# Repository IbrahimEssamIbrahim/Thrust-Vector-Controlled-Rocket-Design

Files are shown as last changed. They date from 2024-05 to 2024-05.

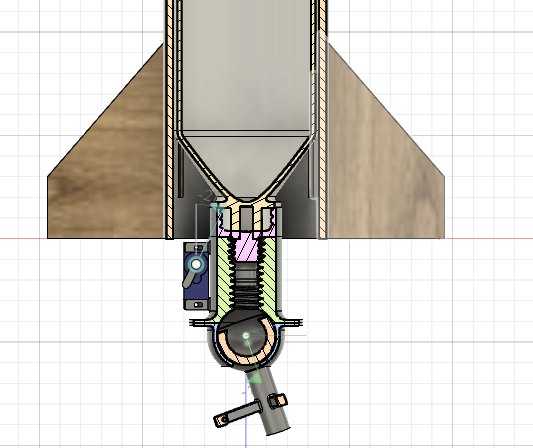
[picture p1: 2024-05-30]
3D&2D_design/3DModels/V0.1/5.png

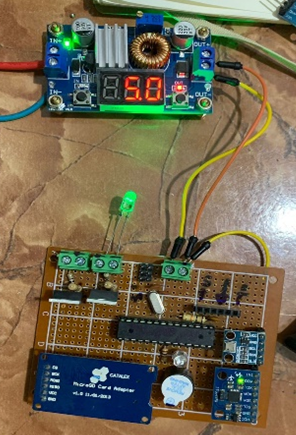
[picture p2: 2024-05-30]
PCBs_RemoteControl_Prototype/PCB_V0.1.png

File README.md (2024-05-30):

# <a href="https://a360.co/3PXAbBp"> Thrust-Vector-Controlled-Rocket-Design </a>

This project proposes the development of a Thrust Vector-Controlled (TVC) rocket as an alternative to drones for high-altitude payload delivery. Drones face limitations such as
cost, payload size restrictions, and reliance on air density, making them inefficient for high-altitude missions. The TVC rocket, inspired by SpaceX's Falcon Heavy, utilizes 
thrust vector control for precise navigation and payload delivery regardless of air density.

The project aims for cost-effectiveness by using off-the-shelf components like pressure sensors, IMUs, and Arduinos, integrated into a single PCB. This approach, coupled with
lightweight 3D-printed materials for the rocket chassis, aims to reduce costs significantly.

Applications include academic research and medical deliveries to remote areas. The rocket's design focuses on stability optimization, utilizing OpenRocket software for
simulations and Fusion 360 for 3D component design. Additionally, a water pressure chamber was introduced for cost-effective testing.

The flight computer comprises various sensors for monitoring acceleration, rotation, and altitude, essential for making critical flight decisions. These include MPU6050 IMUs, 
BMP280 barometers, EEPROMs, and battery level monitors.

Overall, the TVC rocket project offers an affordable and efficient solution for high-altitude payload delivery, potentially revolutionizing academic and humanitarian applications.



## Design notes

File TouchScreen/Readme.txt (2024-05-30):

This file represents an attempt to create a remote touch screen using a TFT 2.4-inch screen. However, the project was discontinued due to limitations with the touch screen module, which occupied all Arduino pins except one. This constraint made it nearly impossible to integrate an NRF transmitter with the Arduino. Instead, the project shifted towards utilizing WiFi with the ESP8266 module.

The TFT 2.4-inch screen libraries contained errors, further complicating the project. While some resources for making the screen work are included in this file, most of the project remains unfinished.

//////////////////////////here is how to solve problem with ///////////////////////////////////

Go to this website to download the library Zip_files ----> 

http://www.lcdwiki.com/2.4inch_Arduino_Display

for better understanding go to ----> https://www.youtube.com/watch?v=_GT_sgbKQrc 

before starting you must make some changes 

in the code change this part 

#define YP A1  // must be an analog pin, use "An" notation!
#define XM A2  // must be an analog pin, use "An" notation!
#define YM 7   // can be a digital pin
#define XP 6   // can be a digital pin 

			TO 

#define YP A3  // must be an analog pin, use "An" notation!
#define XM A2  // must be an analog pin, use "An" notation!
#define YM 9   // can be a digital pin
#define XP 8   // can be a digital pin 

and find Id part and Set it to  --->   tft.begin(0x7575); // SDFP5408

then go to the library file im the documents ---> C:\Users\Ibrahim_Essam\Documents\Arduino\libraries\SPFD5408-master

and change line 163 TO return TSPoint( 1103-x, 1063-y, z);

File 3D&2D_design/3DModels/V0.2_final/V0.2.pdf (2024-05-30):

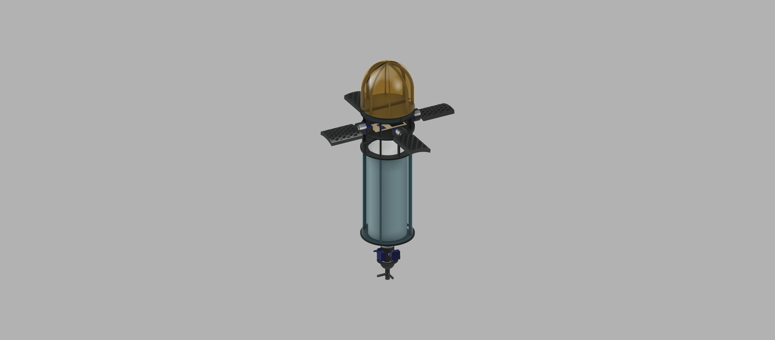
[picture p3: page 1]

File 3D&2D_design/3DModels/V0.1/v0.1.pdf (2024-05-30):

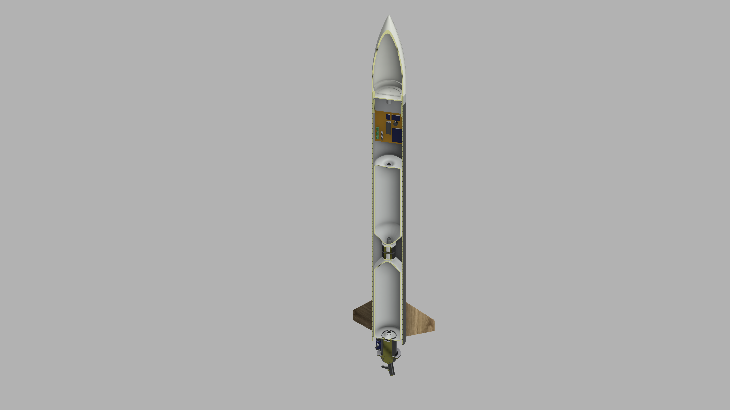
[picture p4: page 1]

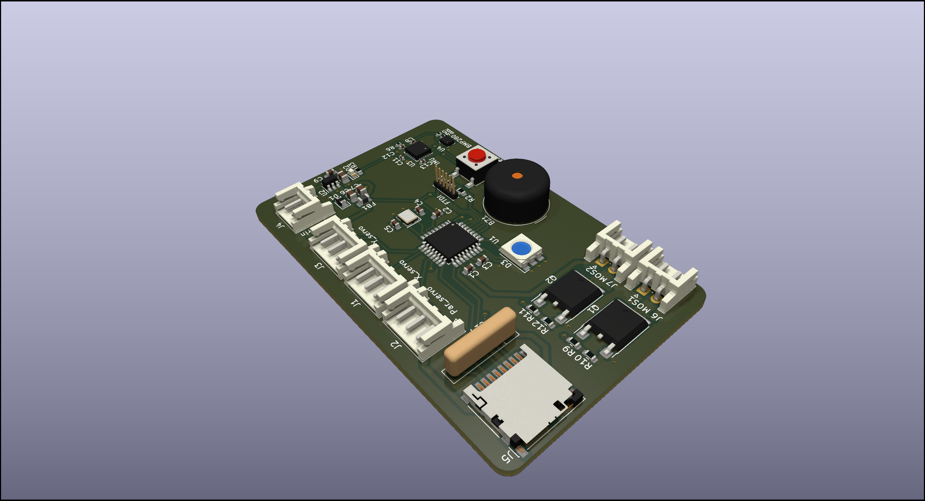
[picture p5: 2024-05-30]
PCBs_RemoteControl_Prototype/3Dview.png

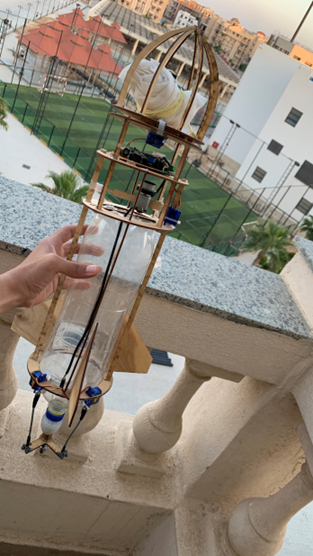
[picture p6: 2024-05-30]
PCBs_RemoteControl_Prototype/final_pro.png

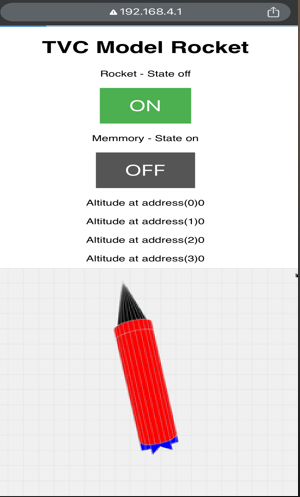
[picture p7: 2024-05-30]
PCBs_RemoteControl_Prototype/WIFI_ControlRemote_withLiveDataView.png

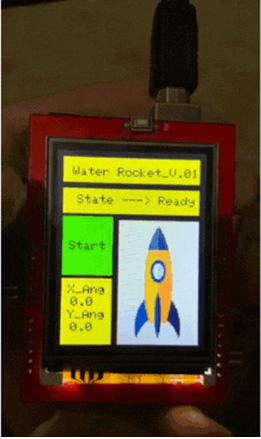
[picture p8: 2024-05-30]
PCBs_RemoteControl_Prototype/RemoteControlWithTouchScreen.png

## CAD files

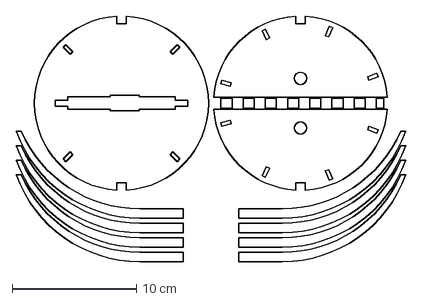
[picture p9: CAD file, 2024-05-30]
3D&2D_design/2D_laserCNC/CNC_Par.dxf
31.3 x 19.7 cm

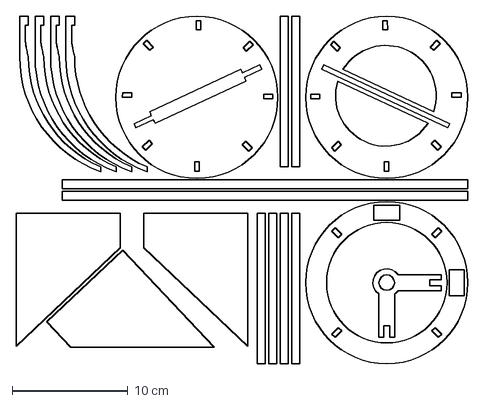
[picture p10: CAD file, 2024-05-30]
3D&2D_design/2D_laserCNC/CNC.dxf
39.0 x 30.0 cm

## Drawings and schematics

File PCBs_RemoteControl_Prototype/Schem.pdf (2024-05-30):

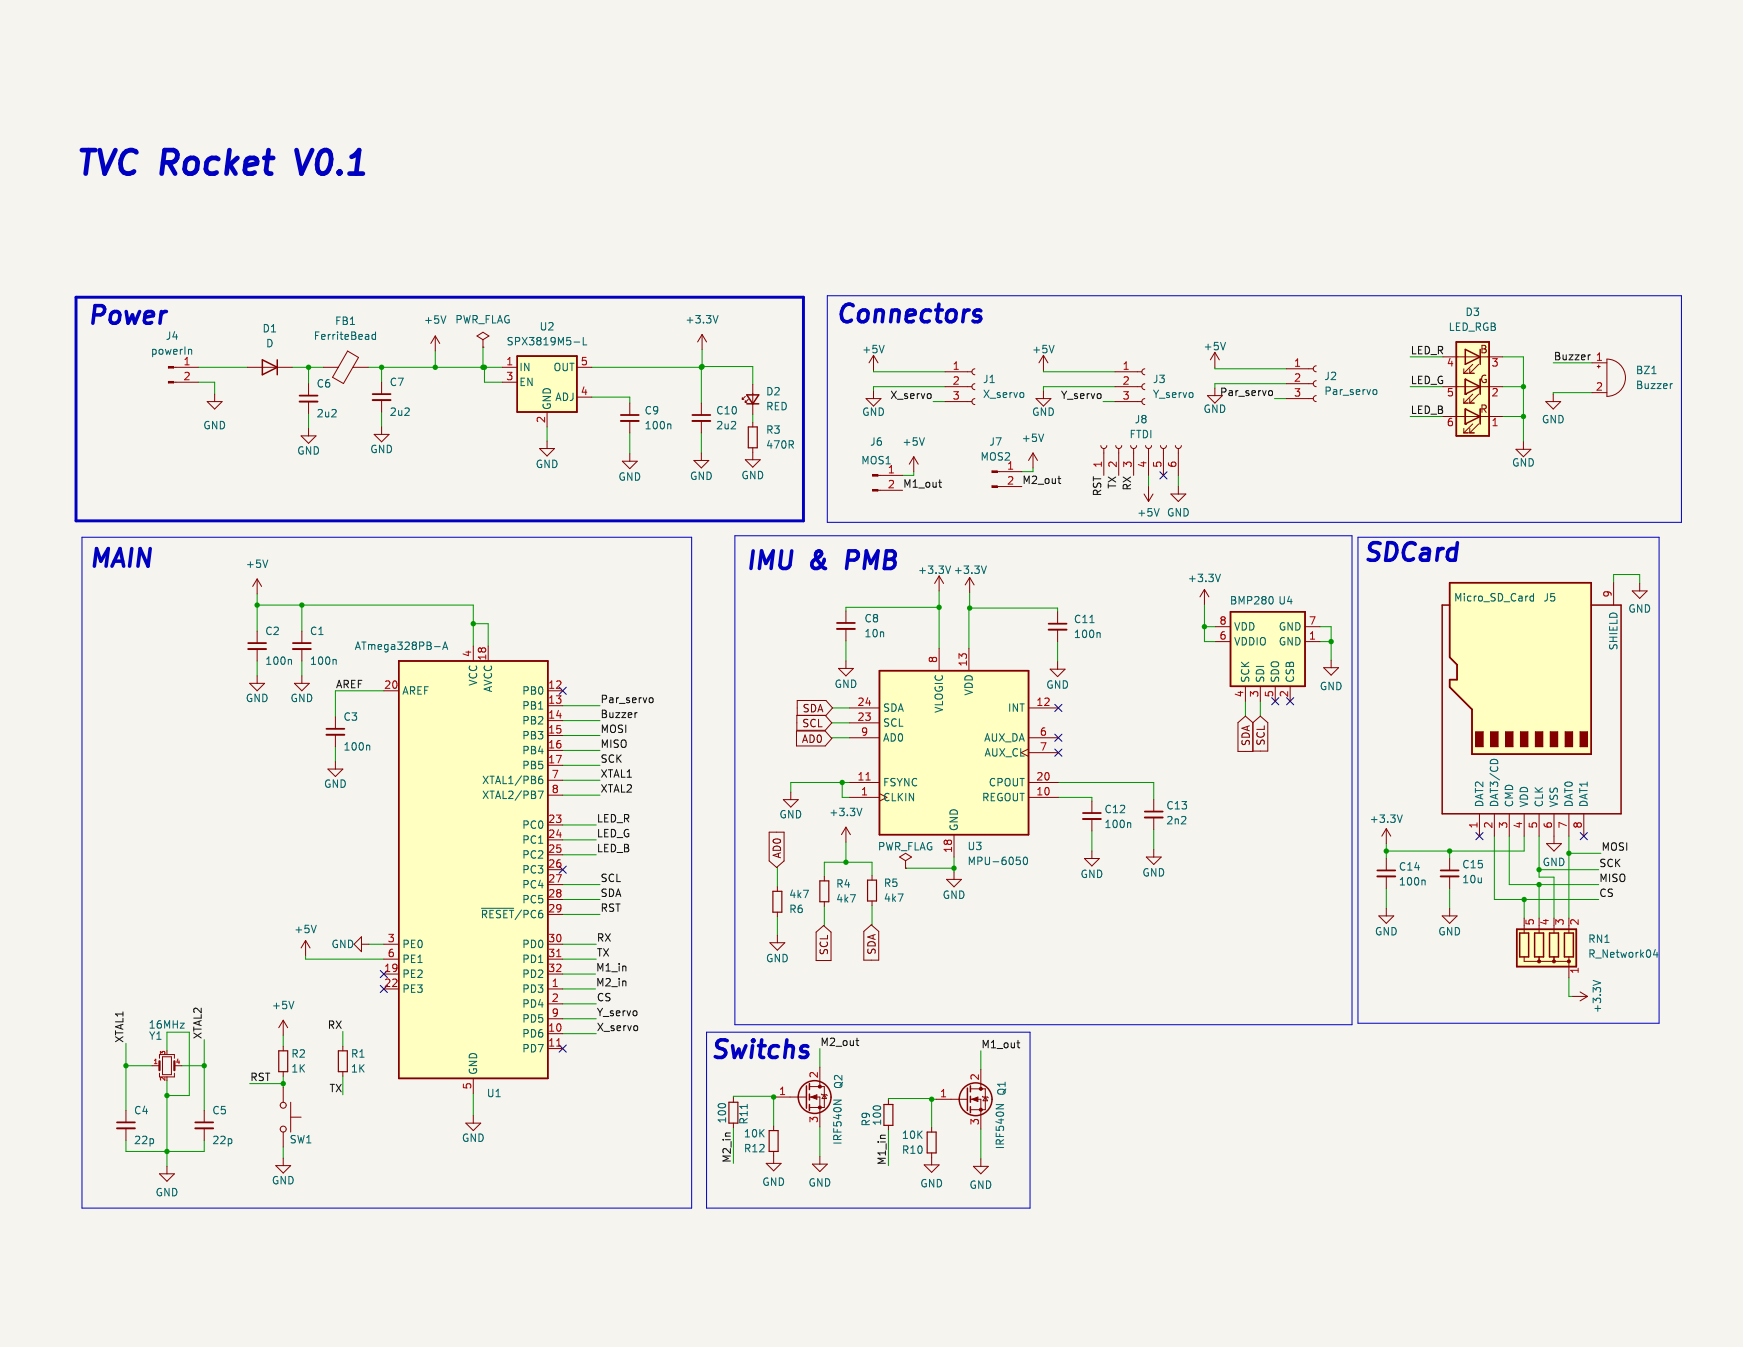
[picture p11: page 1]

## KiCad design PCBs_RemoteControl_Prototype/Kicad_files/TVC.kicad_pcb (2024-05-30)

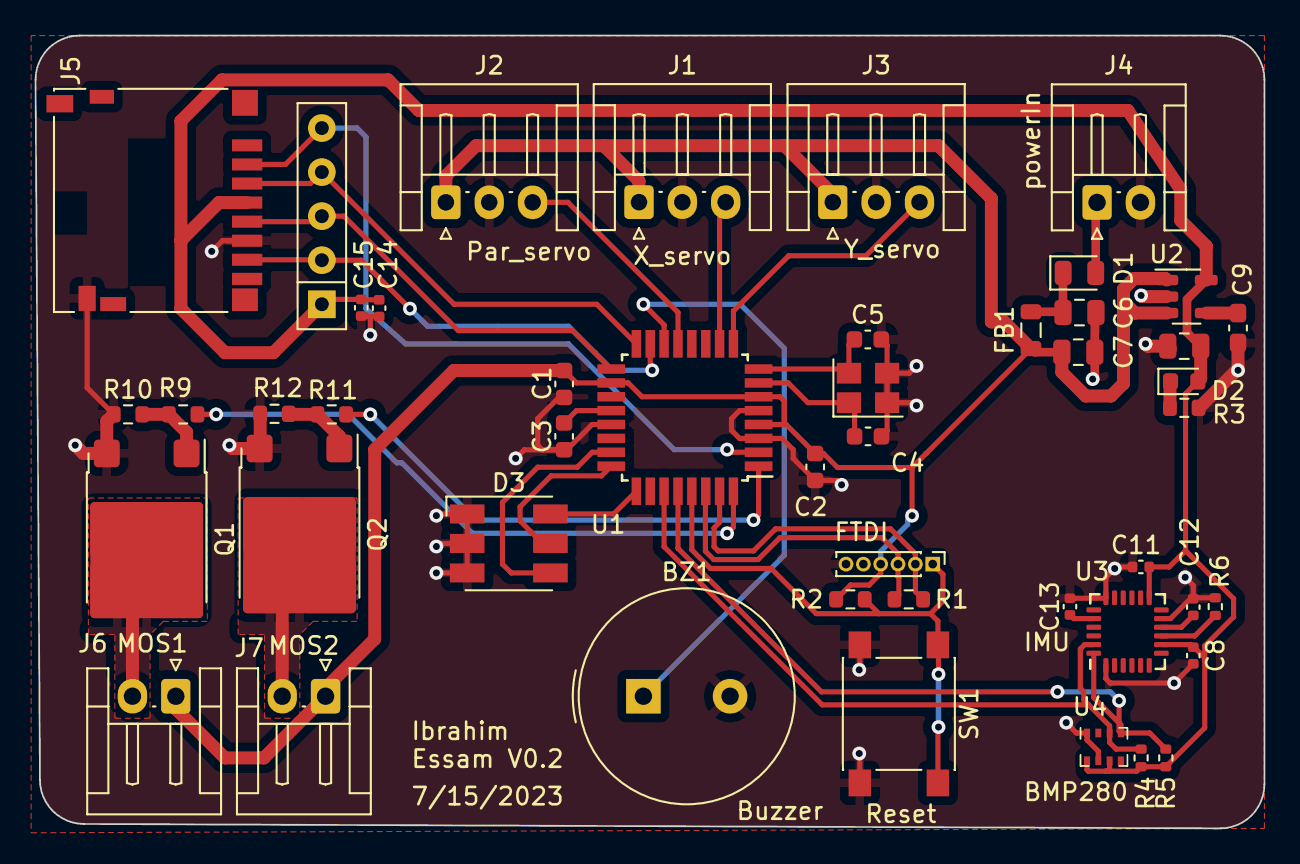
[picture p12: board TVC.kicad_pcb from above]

Board: 2 copper layers, 70.9 x 45.7 mm, 47 parts (0 on the bottom side), 35 nets.

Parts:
BZ1: Buzzer; Buzzer_TDK_PS1240P02BT_D12.2mm_H6.5mm
C1, C2, C3: 100n; C_0603_1608Metric
C4, C5: 22p; C_0603_1608Metric
C6, C7, C10: 2u2; C_0805_2012Metric
C8: 10n; C_0402_1005Metric
C9: 100n; C_0603_1608Metric_Pad1.08x0.95mm_HandSolder
C11, C12, C14: 100n; C_0402_1005Metric
C13: 2n2; C_0402_1005Metric
C15: 10u; C_0402_1005Metric
D1: D; D_0805_2012Metric
D2: RED; LED_0603_1608Metric
D3: LED_RGB; LED_RGB_5050-6
FB1: FerriteBead; L_0805_2012Metric
J1: X_servo; JST_EH_S3B-EH_1x03_P2.50mm_Horizontal
J2: Par_servo; JST_EH_S3B-EH_1x03_P2.50mm_Horizontal
J3: Y_servo; JST_EH_S3B-EH_1x03_P2.50mm_Horizontal
J4: powerIn; JST_EH_S2B-EH_1x02_P2.50mm_Horizontal
J5: Micro_SD_Card; microSD_HC_Hirose_DM3D-SF
J6: MOS1; JST_EH_S2B-EH_1x02_P2.50mm_Horizontal
J7: MOS2; JST_EH_S2B-EH_1x02_P2.50mm_Horizontal
J8: FTDI; PinHeader_1x06_P1.00mm_Vertical
Q1, Q2: IRF540N; ATPAK-2
R1, R2: 1K; R_0603_1608Metric
R3: 470R; R_0603_1608Metric
R4, R5, R6: 4k7; R_0402_1005Metric
R9, R11: 100; R_0603_1608Metric
R10, R12: 10K; R_0603_1608Metric
RN1: R_Network04; R_Array_SIP5
SW1: SW_Push; SW_SPST_PTS645
U1: ATmega328PB-A; TQFP-32_7x7mm_P0.8mm
U2: SPX3819M5-L; SOT-23-5
U3: MPU-6050; InvenSense_QFN-24_4x4mm_P0.5mm
U4: BMP280; Bosch_LGA-8_2x2.5mm_P0.65mm_ClockwisePinNumbering
Y1: 16MHz; Crystal_SMD_3225-4Pin_3.2x2.5mm

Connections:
+3.3V: C8.1, C10.1, C11.1, C14.1, C15.1, D2.2 (A), J5.4 (VDD), R4.1, R5.1, RN1.1 (common), U2.5 (OUT), U3.8 (VLOGIC), U3.13 (VDD), U4.6 (VDDIO), U4.8 (VDD)
+5V: C1.1, C2.1, C7.1, FB1.2, J1.1, J2.1, J3.1, J6.1, J7.1, J8.4, R2.1, U1.4 (VCC), U1.6 (PE1), U1.18 (AVCC), U2.1 (IN), U2.3 (EN)
/AREF: C3.1, U1.20 (AREF)
/Buzzer: BZ1.1 (-), U1.14 (PB2)
/CS: J5.2 (DAT3/CD), RN1.5 (R4), U1.2 (PD4)
/LED_B: D3.6 (RA), U1.25 (PC2)
/LED_G: D3.5 (GA), U1.24 (PC1)
/LED_R: D3.4 (BA), U1.23 (PC0)
/M1_in: R9.1, U1.32 (PD2)
/M1_out: J6.2, Q1.2 (D)
/M2_in: R11.1, U1.1 (PD3)
/M2_out: J7.2, Q2.2 (D)
/MISO: J5.3 (CMD), RN1.4 (R3), U1.16 (PB4)
/MOSI: J5.7 (DAT0), RN1.2 (R1), U1.15 (PB3)
/Par_servo: J2.3, U1.13 (PB1)
/RST: J8.1, R2.2, SW1.1, U1.29 (~RESET/PC6)
/RX: J8.3, R1.1, U1.30 (PD0)
/SCK: J5.5 (CLK), RN1.3 (R2), U1.17 (PB5)
/TX: J8.2, R1.2, U1.31 (PD1)
/XTAL1: C4.1, U1.7 (XTAL1/PB6), Y1.1
/XTAL2: C5.1, U1.8 (XTAL2/PB7), Y1.4
/X_servo: J1.3, U1.10 (PD6)
/Y_servo: J3.3, U1.9 (PD5)
AD0: R6.2, U3.9 (AD0)
GND: BZ1.2 (+), C1.2, C2.2, C3.2, C4.2, C5.2, C6.2, C7.2, C8.2, C9.2, C10.2, C11.2, C12.2, C13.2, C14.2, C15.2, D3.1 (RK), D3.2 (GK), D3.3 (BK), J1.2, J2.2, J3.2, J4.2, J5.6 (VSS), J5.9 (SHIELD), J8.6, Q1.3 (S), Q2.3 (S), R3.2, R6.1, R10.1, R12.1, SW1.2, U1.3 (PE0), U1.5 (GND), U1.21 (GND), U2.2 (GND), U3.1 (CLKIN), U3.11 (FSYNC), U3.18 (GND), U4.1 (GND), U4.7 (GND), Y1.2, Y1.3
unnamed: D1.2 (A), J4.1
unnamed: C6.1, D1.1 (K), FB1.1
unnamed: D2.1 (K), R3.1
unnamed: Q1.1 (G), R9.2, R10.2
unnamed: Q2.1 (G), R11.2, R12.2
unnamed: C9.1, U2.4 (ADJ)
unnamed: C13.1, U3.20 (CPOUT)
unnamed: C12.1, U3.10 (REGOUT)
SCL: R4.2, U1.27 (PC4), U3.23 (SCL), U4.3 (SDI)
SDA: R5.2, U1.28 (PC5), U3.24 (SDA), U4.4 (SCK)
